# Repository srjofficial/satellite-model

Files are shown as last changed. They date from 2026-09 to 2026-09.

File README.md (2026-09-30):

# 🛰️ CubeSat-Style 1U Satellite Working Model








A comprehensive, fully open-source **1U CubeSat educational demonstrator (100 mm cube)** featuring autonomous dual-axis solar tracking, an ESP32-CAM imaging payload, environmental & electrical telemetry, and long-range LoRa packet downlink with automated ground station reassembly.

---

## 🖼️ 3D Model & PCB Previews

| 🛰️ 3D CAD Assembly (OpenSCAD / WebGL) | 🟢 Carrier PCB & Gerber Layout |
|:---:|:---:|
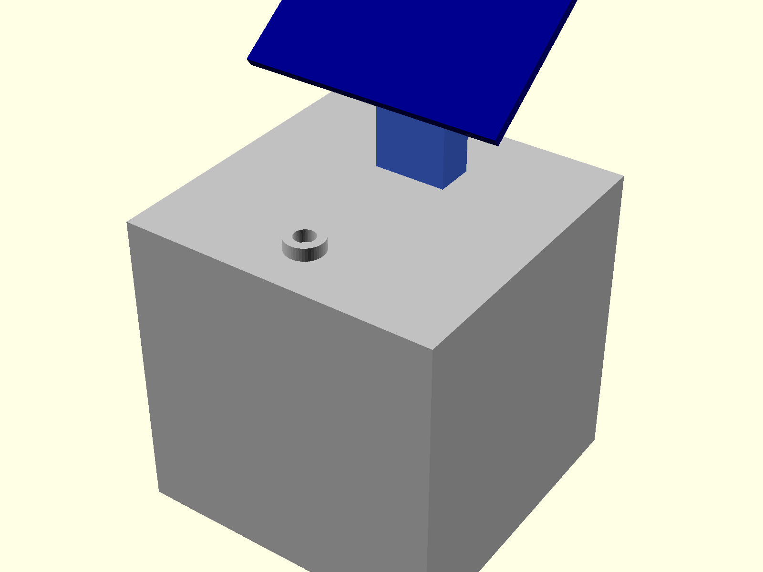
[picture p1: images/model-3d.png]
CubeSat 3D Model
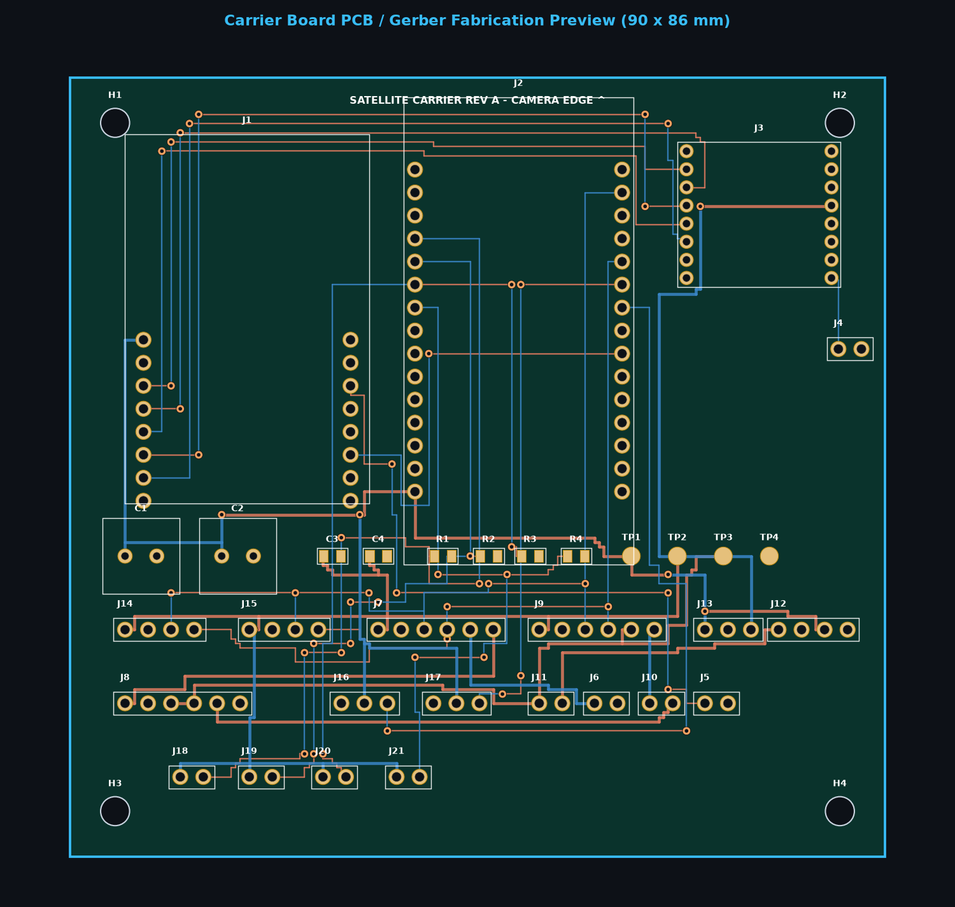
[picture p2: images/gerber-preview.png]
Carrier PCB Gerber Preview
|  |  |
| *100 mm 1U chassis with pan/tilt solar tracker & camera aperture* | *90 × 86 mm 2-layer PCB layout with routed traces, ENIG pads & silkscreen* |

* 🌐 **Interactive 3D Web Viewer:** Open [`cad/view_model.html`](cad/view_model.html) in your browser for full 3D Orbit controls, real-time Pan/Tilt servo simulation, and an **Exploded View**!
* 📦 **PCB Fabrication Files:** Download [`hardware/gerbers.zip`](hardware/gerbers.zip) for instant manufacturing (JLCPCB, PCBWay, OSHPark).
* 🧪 **Proteus Integration:** Tango netlist and simulation guide available in [`hardware/proteus/`](hardware/proteus/).

```powershell
# Open interactive 3D model viewer in your browser
Start-Process "cad\view_model.html"
```

---

## 🚀 Key Features

* **☀️ Autonomous Dual-Axis Solar Tracking:** 4-quadrant LDR contrast bridge driving two SG90/MG90S servos across pan (10°–170°) and tilt (20°–160°) axes with software deadband and smooth 1° increments.
* **📸 Chunked LoRa Imaging Payload:** AI-Thinker ESP32-CAM captures QQVGA (160×120) JPEG stills, slices them into 200-byte packets protected by CRC-16/CCITT-FALSE checksums, and transmits over SX1278 LoRa.
* **⚡ Comprehensive Telemetry Suite:** Dual INA219 sensors (solar generation V/mA and battery charge/discharge V/mA), Bosch BME280 (temperature, atmospheric pressure, relative humidity), and MPU6050 6-DOF IMU (real-time pitch/roll attitude).
* **🔋 Power Management & Duty Cycling:** Single 18650 Li-ion battery charged via TP4056 with DW01 low-voltage protection, 5V boost converter, dedicated 3.3V LDO, and deep-sleep duty cycling on the camera payload.
* **📡 Ground Station & Python Reassembly:** ESP32 + SX1278 receiver firmware that validates hardware & software CRC-16 checksums, paired with a Python application that reconstructs JPEG images and logs synchronized telemetry to CSV.
* **🛠️ Parametric CAD & Carrier PCB:** Parametric OpenSCAD design (`cad/satellite.scad`) matched to a custom 90×86 mm 2-layer KiCad carrier PCB (`hardware/kicad/`) with ground pours, M3 standoffs, and antenna keep-out zones.

---

## 🏗️ System Architecture

```mermaid
flowchart TD
  subgraph EPS["Electrical Power Subsystem (EPS)"]
    SP["☀️ Solar Panel (Max 6V)"] --> J7["INA219 #1 (Solar V & mA)"]
    J7 --> CH["TP4056 Charger + DW01 Protection"]
    CH <--> J9["INA219 #2 (Battery V & +/-mA)"]
    J9 <--> BAT["🔋 18650 Li-ion Cell (3.7V)"]
    CH --> SW["Power Switch"]
    SW --> BST["⚡ 5V Boost Converter"]
    BST --> RAIL5["+5V Power Rail"]
    RAIL5 --> LDO["AMS1117-3.3 LDO"]
    LDO --> RAIL3["+3.3V Power Rail"]
  end

  subgraph OAS["OBC & Attitude Subsystem (Tracker)"]
    RAIL5 --> TRK["ESP32 DevKit 30-Pin"]
    LDR["4x LDR Quadrant Bridge"] --> TRK
    BME["BME280 (Temp/Press/Hum)"] -->|"I2C (0x76)"| TRK
    MPU["MPU6050 (Pitch/Roll)"] -->|"I2C (0x68)"| TRK
    J7 -->|"I2C (0x40)"| TRK
    J9 -->|"I2C (0x41)"| TRK
    TRK -->|"PWM GPIO 18"| SRV1["Pan Servo (10°-170°)"]
    TRK -->|"PWM GPIO 19"| SRV2["Tilt Servo (20°-160°)"]
  end

  subgraph PAYLOAD["Camera Payload & Communications"]
    RAIL5 --> CAM["AI-Thinker ESP32-CAM"]
    RAIL3 --> LORA["SX1278 LoRa Module (433 MHz)"]
    TRK -->|"UART2 115200 (GPIO 17 to GPIO 3)"| CAM
    CAM -->|"HSPI (SCK 14, MISO 12, MOSI 13, NSS 15)"| LORA
  end

  subgraph GROUND["Ground Segment"]
    LORA -.->|"LoRa RF 433 MHz (SF7, BW 125kHz)"| GS_RF["Ground SX1278"]
    GS_RF --> GS_MCU["Ground ESP32 DevKit"]
    GS_MCU -->|"USB Serial (PKT, hex, rssi, snr)"| PY["Python Ground Station App"]
    PY --> CSV["📊 telemetry.csv"]
    PY --> JPG["🖼️ Reassembled JPEGs"]
  end
```

---

## 📦 Downlink Protocol & Packet Format

Telemetry and image chunks are packed into byte frames protected by **CRC-16/CCITT-FALSE** (`poly=0x1021`, `init=0xFFFF`):

| Offset (Bytes) | Field | Description |
|:---:|:---|:---|
| `0` | **Type** | `0x10` = Image Chunk, `0x20` = Telemetry |
| `1` | **Image ID** | Sequential image session ID (0–255, wraps) |
| `2..3` | **Sequence No** | 16-bit big-endian chunk index (0-based) |
| `4..5` | **Total Packets** | 16-bit big-endian total chunk count for image |
| `6` | **Length ($N$)** | Payload length ($\le 200$ bytes) |
| `7 .. 6+N` | **Payload** | Raw JPEG chunk or ASCII CSV telemetry string |
| `7+N .. 8+N` | **CRC-16** | CRC-16/CCITT calculated over bytes `0` through `6+N` |

### Telemetry String Structure
Transmitted over UART from the Tracker MCU to the Camera payload once per second:
```csv
T,solarV,solar_mA,battV,batt_mA,tempC,pressHPa,humPct,pitch,roll,pan,tilt
```

---

## 🗂️ Repository Structure

```
satellite-model/
├── cad/
│   ├── satellite.scad          # Parametric OpenSCAD 1U cube model
│   ├── view_model.html         # Interactive WebGL 3D model viewer
│   └── README.md               # 3D export instructions (STL/STEP)
├── firmware/
│   ├── esp32-cam-node/         # Camera payload, packetizer, LoRa TX, sleep
│   ├── solar-tracker/          # 4-quadrant LDR tracking, I2C sensors, servos
│   └── ground-station/         # ESP32 + LoRa receiver with CRC verification
├── ground-station-ui/
│   ├── ground_station.py       # Python image reassembly & CSV telemetry logger
│   └── requirements.txt        # Python dependencies (pyserial)
├── hardware/
│   ├── bom.csv                 # Detailed Bill of Materials
│   ├── netlist.csv             # Complete pin-to-pin electrical netlist
│   ├── pinmap.md               # Pin assignment documentation
│   └── kicad/
│       ├── generate_kicad.py   # Algorithmic router & KiCad project generator
│       ├── satellite.kicad_sch # Carrier board schematic
│       ├── satellite.kicad_pcb # Routed 2-layer PCB (90x86 mm)
│       ├── satellite.kicad_pro # KiCad 8 project configuration
│       ├── satellite.pretty/   # Custom footprints
│       └── pcb-preview.png     # Rendered PCB preview
└── docs/
    ├── architecture.md         # Subsystem dataflow & packet specification
    ├── power-budget.md         # Power consumption estimates & duty cycle formula
    ├── test-results.md         # Test result template
    └── linkedin-post.md        # Summary post template
```

---

## 🔧 Bill of Materials (BOM)

| Ref | Component | Description | Qty |
|---|---|---|:---:|
| **U1 / J1** | AI-Thinker ESP32-CAM | Camera payload node (OV2640) | 1 |
| **U2 / J2** | ESP32 DevKit (30-pin) | Solar tracker & telemetry aggregator | 1 |
| **U3 / J3** | SX1278 Ra-02 (433 MHz) | LoRa transceiver module (satellite node) | 1 |
| **U4** | SX1278 Ra-02 + ESP32 | Ground station receiver node | 1 |
| **SEN1 / J7** | INA219 Breakout | Solar current & voltage monitor (`0x40`) | 1 |
| **SEN2 / J9** | INA219 Breakout | Battery current & voltage monitor (`0x41`, solder A0) | 1 |
| **SEN3 / J14**| BME280 Breakout | Temperature, pressure, humidity (`0x76`) | 1 |
| **SEN4 / J15**| MPU6050 Breakout | 6-DOF Gyro & Accelerometer (`0x68`) | 1 |
| **ACT1, ACT2**| SG90 or MG90S | Pan & Tilt servos | 2 |
| **PWR1 / J8** | TP4056 Module | Li-ion charger with DW01 protection | 1 |
| **PWR2 / J12**| MT3608 Boost Module | 3.7V to 5.0V step-up DC-DC converter | 1 |
| **PWR3 / J13**| AMS1117-3.3 Module | 5.0V to 3.3V dedicated LDO | 1 |
| **BAT / J10** | 18650 Li-ion Cell | 3.7V nominal, 2000–3000 mAh + holder | 1 |
| **PV / J6** | Mini Solar Panel | $\le 6\text{ V}$ open circuit (50–150 mA) | 1 |
| **LDR1–4** | GL5528 LDR + 10k 0805 | Quadrant light detection dividers | 4 |
| **C1, C2** | 470 µF 10V Radial | 5V rail bulk capacitors for servo surge absorption | 2 |

---

## ⚡ Setup & Flashing Instructions

### 1. Arduino IDE Setup
Install the **ESP32 Board Package** in Arduino IDE and install the following libraries via the Library Manager:
* `LoRa` (by Sandeep Mistry)
* `ESP32Servo` (by Kevin Harrington)
* `Adafruit INA219`
* `Adafruit BME280 Library`
* `Adafruit MPU6050`
* `Adafruit Unified Sensor`

### 2. Flashing the Tracker Node
1. Open [`firmware/solar-tracker/solar-tracker.ino`](firmware/solar-tracker/solar-tracker.ino).
2. Board: **ESP32 Dev Module** (30-pin DevKit).
3. Connect USB and click **Upload**.

### 3. Flashing the ESP32-CAM Node
> ⚠️ **IMPORTANT:** Disconnect the tracker telemetry line (`ESP32-CAM RX / GPIO 3`) and short `GPIO 0` to `GND` before powering on to enter flashing mode.
1. Open [`firmware/esp32-cam-node/esp32-cam-node.ino`](firmware/esp32-cam-node/esp32-cam-node.ino).
2. Board: **AI Thinker ESP32-CAM**.
3. Upload using an external USB-to-UART adapter (5V, GND, U0TXD, U0RXD).
4. Remove the `GPIO 0` to `GND` jumper and reconnect the telemetry wire after flashing.

### 4. Flashing the Ground Station
1. Open [`firmware/ground-station/ground-station.ino`](firmware/ground-station/ground-station.ino).
2. Connect the ground station ESP32 and click **Upload**.

### 5. Running the Ground Station App
```bash
# Navigate to the ground station directory
cd ground-station-ui

# Install dependencies
pip install -r requirements.txt

# Run the receiver (replace COM5 with your port, or /dev/ttyUSB0 on Linux/macOS)
python ground_station.py --port COM5
```
* **Telemetries:** Appended in real-time to `received/telemetry.csv` with timestamps, signal RSSI, and SNR.
* **Images:** Fully reassembled JPEGs saved automatically to `received/img_<id>_<timestamp>.jpg`.

---

## 📊 Power Budget & Battery Life

| Subsystem / Component | State | Current @ 5V / 3.3V |
|---|---|:---:|
| **ESP32 DevKit (Tracker)** | Active (Tracking & Reading Sensors) | ~50–70 mA |
| **Dual Servos (SG90/MG90S)**| Moving / Idle | ~150–500 mA (peak) / ~10 mA |
| **Sensors (INA219 x2, BME280, MPU6050)** | Active I2C | ~5 mA |
| **ESP32-CAM (Payload)** | Capture & LoRa TX (~5–8s burst) | ~200–280 mA |
| **ESP32-CAM (Payload)** | Deep Sleep (Duty cycle between shots) | ~6–8 mA |

* **Duty Cycle Formula:**
  $$I_{\text{avg}} = \frac{I_{\text{active}} \cdot t_{\text{active}} + I_{\text{sleep}} \cdot t_{\text{sleep}}}{t_{\text{active}} + t_{\text{sleep}}}$$
* With an average consumption of ~120 mA and a single 2500 mAh 18650 cell, expected continuous operation without sunlight is **16–20+ hours**, extended indefinitely under active solar tracking.

---

## 📜 License

This project is open-source under the [MIT License](LICENSE).
Feel free to use it for academic, research, or personal educational projects!

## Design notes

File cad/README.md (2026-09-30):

# CAD

`satellite.scad` is a parametric OpenSCAD model: 100 mm hollow cube body, camera window, antenna mount, bottom plate with PCB standoffs, and a pan/tilt servo mount holding a solar panel.

Export STL:
```
openscad -D 'part="body"' -o body.stl satellite.scad
openscad -D 'part="base"' -o base.stl satellite.scad
openscad -D 'part="tracker"' -o tracker.stl satellite.scad
```
Add `.stl` (and `.step` if exported from FreeCAD) files here. Check dimensions against your real servos and panel before printing. The tracker part is a visual mount; the printable bracket needs fitting to your servo horn.

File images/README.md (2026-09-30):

Add here: build photos, wiring photo, `demo.gif`, received sample images, 3D render (`assembly.png`), block diagram.

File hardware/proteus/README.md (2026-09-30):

# Proteus Design Suite Guide

## Why is `.pdsprj` not directly included?
A `.pdsprj` file is a **proprietary, compiled binary archive** created by Labcenter Electronics Proteus. Inside the `.pdsprj` container are closed-source compiled database files (`ROOT.DSN` for ISIS and `LAYOUT.LYT` for ARES) that can **only be created natively by the Proteus software engine itself**. Any third-party file manually named `.pdsprj` will produce a "Corrupt or invalid project file" error in Proteus.

---

## How to use this project in Proteus

### 1. View the PCB in Proteus Gerber Viewer
Proteus has a built-in Gerber & Excellon viewer:
1. Open **Proteus**.
2. Click **Gerber Viewer** on the startup page (or go to `Output` > `Gerber/Excellon Output` > `Launch Gerber Viewer`).
3. Click `File` > `Open Gerber` and select the files from `hardware/gerbers/` (or extract `hardware/gerbers.zip`).
4. Proteus will render all copper layers, solder masks, silkscreen, and drill holes.

### 2. Import Netlist into Proteus ARES (PCB Layout)
If you want to route or modify the carrier board in Proteus ARES:
1. In Proteus, open **ARES PCB Layout**.
2. Go to `Tools` > `Netlist Compiler` (or `File` > `Import Netlist`).
3. Select `satellite_tango.net` (standard Tango netlist format provided in this directory).
4. Assign footprints for the module headers (`J1` to `J21`, passives `R1-R4`, `C1-C4`).
5. Proteus will load all 24 connected electrical nets.

### 3. Simulating the Circuit in Proteus ISIS
To simulate the CubeSat subsystems in Proteus ISIS:
* **Microcontroller:** Place an `ESP32-WROOM-32` or `Arduino Uno/Nano` (available in the Proteus component library).
* **Solar Tracker:** Place 4 `TORCH_LDR` components in a bridge with four `10k` resistors to analog ADC pins (`IO34, IO35, IO32, IO33`), and connect two `MOTOR-SERVO` components to PWM pins `IO18` and `IO19`.
* **Firmware:** Load the compiled `.hex` or `.bin` from Arduino IDE (`firmware/solar-tracker/`) into the microcontroller properties.

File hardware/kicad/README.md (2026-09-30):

# KiCad project (carrier board, rev A)

Open `satellite.kicad_pro` in **KiCad 8 or newer**.

| File | Contents |
|---|---|
| `satellite.kicad_sch` | Schematic: every module as a header symbol, nets joined by labels |
| `satellite.kicad_pcb` | 90 x 86 mm 2-layer board, placed and routed, GND pour on both layers, antenna keep-out |
| `satellite.pretty/` | Footprints (headers, module sockets, 0805, radial cap, test point, M3 hole) |
| `generate_kicad.py` | Regenerates everything above and `../netlist.csv` (`python3 generate_kicad.py`) |
| `pcb-preview.png` | Picture of the routed board |

## How the board works
Nothing is soldered directly to the board except headers and small passives. Modules (ESP32-CAM, ESP32 DevKit, Ra-02 LoRa, TP4056, boost, LDO, INA219 x2, BME280, MPU6050) plug into or wire to headers. Servos, LDRs, solar panel, battery holder and switch connect through 2-3 pin headers.

Mounting holes: M3 at 80 x 76 mm spacing (matches `cad/satellite.scad`). The top edge (y = 0) is the camera edge.

## First steps in KiCad
1. Open the PCB, press **B** to fill zones, then run **Inspect > Design Rules Checker**.
2. Open the schematic, run **Inspect > Electrical Rules Checker**. Expect warnings about passive pins; every pin is typed "passive" on purpose.
3. **Tools > Update PCB from Schematic** should report no changes.
4. Check the 3D viewer, then **File > Fabrication Outputs > Gerbers/Drill** and save to `gerbers/`.

## What was and was not checked
Checked by script: file syntax (balanced S-expressions), every schematic label sits on a pin, all 24 signal/power nets routed, minimum copper clearance 0.216 mm against a 0.2 mm rule, nothing inside the antenna keep-out or near the edge.

**Not checked:** I could not open these files in KiCad itself. Expect small load or DRC surprises. Fix them in KiCad rather than re-running the script if you have already edited the board.

## Verify before ordering a board
- **Module pinouts vary by clone.** Compare the ESP32-CAM, DevKit, Ra-02, INA219 and TP4056 pin order and row spacing against your actual modules. Row spacing is set in `generate_kicad.py` (`ROW_CAM`, `ROW_DEV`); edit and re-run.
- Servo and boost traces are 0.8 mm; signals 0.4 mm. Servo stall current can exceed what one 18650 through a boost converter delivers. Keep the 470 uF capacitors.
- The battery path goes through INA219 #2 (0.1 ohm shunt), so peak load current drops roughly 0.1 V per amp.
- GPIO12 (LoRa MISO) is an ESP32 boot-strap pin and GPIO2 (LoRa RESET) must be low or floating to flash; unplug the LoRa module if flashing fails.
- Label the board "untested design" until built and tested.

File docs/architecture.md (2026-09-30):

# Architecture

## Subsystems
1. **Power (EPS):** Solar panel -> TP4056 (protected) -> 18650 -> 5 V boost -> both ESP32 boards. Dedicated 3.3 V LDO for LoRa + I2C sensors.
2. **Attitude/solar tracking:** 4-quadrant LDR bridge read by ESP32 ADC. Top/bottom difference drives tilt servo, left/right difference drives pan servo (1 degree steps, deadband).
3. **Payload:** ESP32-CAM captures QQVGA JPEG on a timer.
4. **Comms:** SX1278 LoRa (SF7, BW 125 kHz, CR 4/5). Packets carry CRC-16/CCITT.
5. **Ground segment:** ESP32 + SX1278 forwards verified packets over USB serial; Python reassembles.

## Data flow
Tracker (1 Hz) --UART text--> CAM node. CAM wakes from deep sleep every `SLEEP_SECONDS`, grabs the latest telemetry line, captures an image, transmits telemetry packet + image chunks, sleeps.

## Packet format (big-endian)
| Bytes | Field |
|---|---|
| 1 | type: `0x10` image data, `0x20` telemetry |
| 1 | image id (wraps at 255) |
| 2 | sequence number (0-based) |
| 2 | total packets |
| 1 | payload length |
| N | payload (<= 200 B) |
| 2 | CRC-16/CCITT-FALSE over all previous bytes |

## Telemetry line
`T,solarV,solarmA,battV,battmA,tempC,pressHPa,humPct,pitch,roll,pan,tilt`

## Block diagram
Export the Mermaid diagram in the README to `docs/block-diagram.png` (mermaid.live) and commit it.

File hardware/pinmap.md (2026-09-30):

# Pin Map

Board references (J1, J2...) match `hardware/kicad/`. Full connection list: `netlist.csv` (generated from the same table as the schematic and PCB).

## ESP32-CAM (AI-Thinker), J1 - camera node
| Signal | GPIO | Connects to |
|---|---|---|
| LoRa SCK | 14 | SX1278 SCK |
| LoRa MISO | 12 | SX1278 MISO |
| LoRa MOSI | 13 | SX1278 MOSI |
| LoRa NSS | 15 | SX1278 NSS |
| LoRa RST | 2 | SX1278 RESET |
| LoRa DIO0 | not used | TX-only firmware |
| Telemetry RX (UART0) | 3 | Tracker GPIO17 (disconnect when flashing) |
| Flash jumper | 0 | J5 (short IO0 to GND only while flashing) |
| 5V / GND | - | Boost output / GND |
| 3V3 for LoRa | - | Dedicated 3.3 V LDO (J13); the board's own 3V3 pin is left unconnected |

## ESP32 DevKit, J2 - tracker
| Signal | GPIO |
|---|---|
| Pan servo (J16) | 18 |
| Tilt servo (J17) | 19 |
| LDR TL / TR / BL / BR (J18-J21) | 34 / 35 / 32 / 33 |
| I2C SDA / SCL | 21 / 22 |
| UART2 TX (to CAM RX) | 17 |

I2C devices: INA219 solar (J7) 0x40, INA219 battery (J9) 0x41 (solder A0), BME280 (J14) 0x76, MPU6050 (J15) 0x68.

LDR wiring: 3.3 V -> LDR (J18-J21) -> ADC pin -> 10 kOhm (R1-R4) -> GND.

## Power path
Solar (J6) -> INA219 (J7) -> TP4056 IN -> TP4056 B+ -> INA219 (J9) -> 18650 (J10). Load takes TP4056 OUT+ -> switch (J11) -> 5 V boost (J12) -> 5 V rail -> 3.3 V LDO (J13).

TP4056 header (J8) pin order matches standard protected module pads:
1: IN+, 2: IN-, 3: OUT+, 4: B+, 5: B-, 6: OUT-.

## SX1278 Ra-02, J3 and ground station
Note for J3 on carrier board: Verify your Ra-02 breakout module pinout against J3 before soldering (bare modules use 2.0 mm pitch; check pin assignments).
Ground-station ESP32 DevKit wiring (separate, not on this board):

| Signal | GPIO |
|---|---|
| SCK / MISO / MOSI | 18 / 19 / 23 |
| NSS / RST / DIO0 | 5 / 14 / 26 |

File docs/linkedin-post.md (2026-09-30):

# 🚀 LinkedIn Post Templates

Here are ready-to-publish post templates crafted for maximum engagement, showcasing both hardware engineering and embedded software skills.

---

## 🌟 Option 1: Engineering Story & Technical Deep Dive (Recommended)

Can you transmit images from a satellite using only long-range radio (LoRa)? 🛰️📡

I recently engineered a functional **1U CubeSat Satellite Model (100 mm cube)** from scratch—combining embedded systems, custom PCB design, solar tracking, and a long-range downlink.

Here’s how the subsystems work together:

☀️ **Dual-Axis Solar Tracker:**
A 4-quadrant LDR contrast bridge and ESP32 DevKit compute sunlight differentials to steer dual micro-servos across pan (10°–170°) and tilt (20°–160°) angles with software deadbanding.

📸 **Payload & LoRa Image Downlink:**
LoRa runs at low bitrates (~5 kbps at SF7/125kHz), making live video impossible. Instead, I designed a chunked downlink protocol: an AI-Thinker ESP32-CAM captures QQVGA (160x120) JPEG stills, slices them into 200-byte packets protected by CRC-16/CCITT-FALSE checksums, and transmits them over a 433 MHz SX1278 transceiver.

⚡ **Electrical Power Subsystem (EPS):**
A single 18650 Li-ion cell charged via TP4056 + DW01 protection, stepped up to 5V (MT3608) and 3.3V (AMS1117). Real-time solar and battery power telemetry are monitored using dual INA219 current/voltage sensors, while the camera node duty-cycles into deep sleep to maximize battery life.

📊 **Sensors & Ground Station:**
Monitors attitude via MPU6050 (pitch/roll) and environment via BME280 (temperature, atmospheric pressure, relative humidity). A dedicated ground station receiver forwards verified packets over USB serial to a custom Python desktop application that logs telemetry to CSV and automatically reassembles incoming JPEG images.

🛠️ **Hardware & CAD:**
- Designed a custom 90×86 mm 2-layer carrier PCB in KiCad 8.0 with dedicated ground pours and antenna keep-outs.
- Modeled a parametric 1U enclosure in OpenSCAD with an interactive WebGL 3D viewer built with Three.js.

Huge thanks to the open-source hardware community for making space technology concepts accessible for hands-on learning.

🔗 Full source code, schematics, and CAD files on GitHub:
https://github.com/srjofficial/satellite-model

#EmbeddedSystems #CubeSat #ESP32 #LoRa #PCBDesign #HardwareEngineering #OpenSource #IoT #KiCad #Arduino #SpaceTech

---

## ⚡ Option 2: Short & Punchy Portfolio Showcase

Thrilled to share my latest hardware & firmware project: a functional **1U CubeSat Satellite Working Model**! 🛰️⚡

Key features:
✅ Autonomous dual-axis solar tracking (4-quadrant LDR + dual servos)
✅ ESP32-CAM payload transmitting compressed JPEGs over SX1278 LoRa (433 MHz)
✅ CRC-16 protected packet protocol with automated Python image reassembly
✅ Comprehensive telemetry: Dual INA219 (V/I), BME280 (P/T/H), MPU6050 (attitude)
✅ Custom 2-layer KiCad 8 carrier PCB + parametric OpenSCAD 3D chassis

One of the best engineering lessons on this build was architecting around bandwidth constraints—turning a low-throughput LoRa radio into a reliable image downlink using custom chunking and CRC validation.

Check out the full repository (code, CAD, and schematics):
👉 https://github.com/srjofficial/satellite-model

#IoT #Embedded #ESP32 #CubeSat #Electronics #AerospaceEngineering #Robotics #Hardware

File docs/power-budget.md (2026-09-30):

# Power Budget

Values below are **typical datasheet-level estimates. Replace with your INA219 measurements.**

| Load | Mode | Current (mA) | Notes |
|---|---|---|---|
| ESP32-CAM | capture + processing | ~150-200 | camera on |
| SX1278 | TX 17 dBm | ~90-120 | during packets only |
| ESP32-CAM | deep sleep | ~6-10 | AI-Thinker board overhead |
| ESP32 DevKit tracker | active | ~50-80 | WiFi/BT off |
| Servos | idle / moving | ~10 / 150-500 | move rarely |
| Sensors (INA219, BME280, MPU6050) | active | ~5 | |

## Battery
18650 nominal ~2000-3000 mAh at 3.7 V. Boost efficiency ~85%.

## Duty-cycle formula
`I_avg = (I_active * t_active + I_sleep * t_sleep) / (t_active + t_sleep)`

Fill in measured values:

| Cycle time | t_active (s) | I_avg (mA) | Runtime without sun (h) |
|---|---|---|---|
| 60 s | TBD | TBD | TBD |
| 300 s | TBD | TBD | TBD |

## Solar
Panel: TBD V / TBD mA. Measure charge current at noon vs. tracker fixed vs. tracking on.

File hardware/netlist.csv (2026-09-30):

net | pins
GND | J1.2(GND), J1.12(GND), J1.16(GND), J2.14(GND), J2.29(GND), J3.1(GND), J3.8(GND), J3.10(GND), J4.2(GND), J5.2(GND), J6.2(PV-), J7.2(GND), J8.2(IN-), J8.6(OUT-), J9.2(GND), J12.2(VIN-), J12.4(VOUT-), J13.2(GND), J14.2(GND), J15.2(GND), J16.1(GND), J17.1(GND), R1.2(2), R2.2(2), R3.2(2), R4.2(2), C1.2(-), C2.2(-), C3.2(2), C4.2(2), TP4.1(1)
+5V | J1.1(5V), J2.15(VIN), J12.3(VOUT+), J13.1(VIN), J16.2(V+), J17.2(V+), C1.1(+), C2.1(+), TP1.1(1)
LORA_MISO | J1.3(IO12), J3.2(MISO)
LORA_MOSI | J1.4(IO13), J3.3(MOSI)
LORA_NSS | J1.5(IO15), J3.5(NSS)
LORA_SCK | J1.6(IO14), J3.4(SCK)
LORA_RST | J1.7(IO2), J3.6(RESET)
CAM_IO0 | J1.11(IO0), J5.1(IO0)
UART_TELEM | J1.14(U0R), J2.24(IO17_TX2)
LDR_TL | J2.4(IO34), J18.2(SIG), R1.1(1)
LDR_TR | J2.5(IO35), J19.2(SIG), R2.1(1)
LDR_BL | J2.6(IO32), J20.2(SIG), R3.1(1)
LDR_BR | J2.7(IO33), J21.2(SIG), R4.1(1)
I2C_SCL | J2.17(IO22), J7.3(SCL), J9.3(SCL), J14.3(SCL), J15.3(SCL)
I2C_SDA | J2.20(IO21), J7.4(SDA), J9.4(SDA), J14.4(SDA), J15.4(SDA)
SERVO_TILT | J2.21(IO19), J17.3(SIG)
SERVO_PAN | J2.22(IO18), J16.3(SIG)
LORA_ANT | J3.9(ANT), J4.1(ANT)
+3V3 | J3.13(3V3), J7.1(VCC), J9.1(VCC), J13.3(VOUT), J14.1(VCC), J15.1(VCC), J18.1(3V3), J19.1(3V3), J20.1(3V3), J21.1(3V3), C3.1(1), C4.1(1), TP2.1(1)
SOLAR_IN | J6.1(PV+), J7.5(VIN+)
SOLAR_OUT | J7.6(VIN-), J8.1(IN+)
TP_BP | J8.3(OUT+), J8.4(B+), J9.5(VIN+), J11.1(IN), TP3.1(1)
BAT_NEG | J8.5(B-), J10.2(BAT-)
BAT_POS | J9.6(VIN-), J10.1(BAT+)
VBAT_SW | J11.2(OUT), J12.1(VIN+)

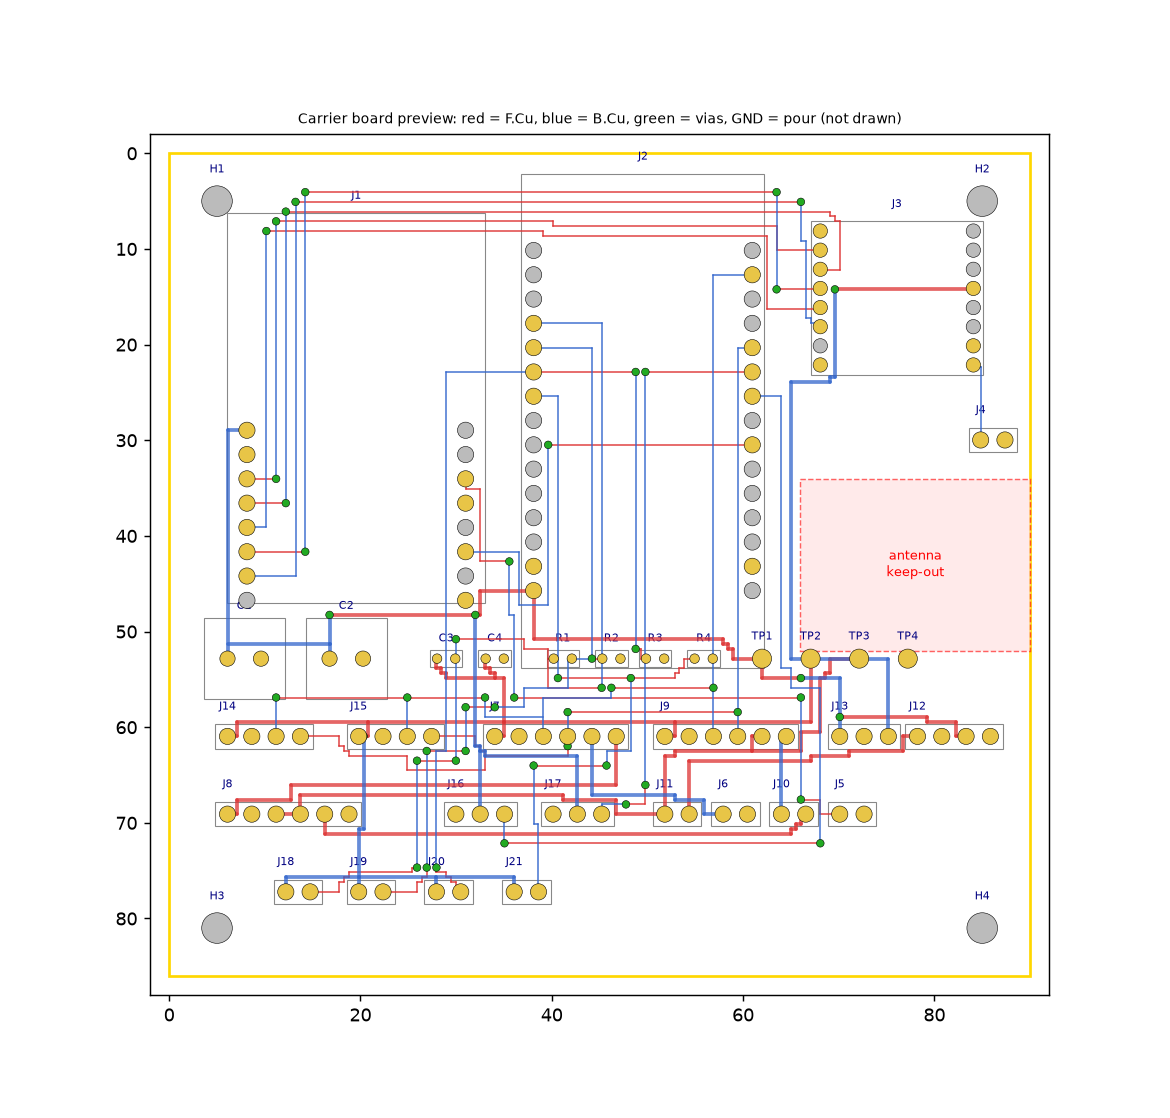
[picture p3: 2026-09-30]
hardware/kicad/pcb-preview.png

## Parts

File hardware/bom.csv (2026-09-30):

ref | part | qty | notes
J1 | AI-Thinker ESP32-CAM + 2x 1x8 female header | 1 | camera node
J2 | ESP32 DevKit 30-pin + 2x 1x15 female header | 1 | tracker/telemetry; check row spacing
J3 | SX1278 Ra-02 433 MHz module | 1 | solder to board or use 2.0 mm adapter; second one for ground station
J4 | 1x2 pin header | 1 | LoRa antenna pigtail / wire
J5 J6 J10 J11 | 1x2 pin header | 4 | flash jumper / solar / battery holder / switch
J7 J9 | INA219 breakout + 1x6 header | 2 | set second to 0x41 (solder A0)
J8 | TP4056 module with DW01 protection + 1x6 header | 1
J12 | 5V boost module (MT3608 or similar) + 1x4 header | 1 | set 5.0 V before connecting
J13 | 3.3V LDO module (AMS1117-3.3) + 1x3 header | 1
J14 J15 | BME280 and MPU6050 breakouts + 1x4 header | 2 | BME280 address 0x76
J16 J17 | SG90 or MG90S servo + 1x3 header | 2 | pan / tilt
J18-J21 | LDR (GL5528 or similar) + 1x2 header | 4 | quadrant sun sensor
R1-R4 | 10k 0805 resistor | 4 | LDR dividers
C1 C2 | 470 uF 10 V radial 8 mm | 2 | 5 V bulk
C3 | 10 uF 0805 | 1 | 3.3 V
C4 | 100 nF 0805 | 1 | 3.3 V
TP1-TP4 | Test pad 2 mm | 4 | +5V / +3V3 / VBAT / GND
H1-H4 | M3 screw + 6 mm standoff | 4
PV1 | Solar panel 5-6V small | 1 | open-circuit voltage must stay <= 6 V
BT1 | 18650 cell + holder | 1 | protected cell recommended
ANT1 | 433 MHz antenna | 2 | one per LoRa module
- | 3D-printed frame (PLA/PETG) | 1 | see cad/

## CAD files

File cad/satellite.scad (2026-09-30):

// CubeSat-style 1U-ish model (100 mm cube), parametric.
// Export: openscad -D 'part="body"' -o body.stl satellite.scad
// part = "assembly" | "body" | "base" | "tracker" | "panel"
part = "assembly";
$fn = 48;
S = 100;        // cube size
W = 2.5;        // wall
tilt = 35;      // panel tilt for preview

module servo() {
  color("royalblue") cube([23, 12.5, 22.5], center = true);
  color("white") translate([0, 0, 11.25]) cylinder(d = 6, h = 4);
}

module panel() { color("navy") cube([80, 60, 3], center = true); }

module body() {
  difference() {
    cube([S, S, S], center = true);
    // hollow, open bottom for assembly
    translate([0, 0, -W / 2]) cube([S - 2 * W, S - 2 * W, S - W + 0.02], center = true);
    // camera window on +Y face (offset -25.6 mm to align with PCB socket J1)
    translate([-25.6, S / 2 - W / 2, -26]) rotate([90, 0, 0]) cylinder(d = 14, h = W + 2, center = true);
    // power switch slot on -X face
    translate([-S / 2, 0, -20]) cube([W * 2 + 1, 12, 7], center = true);
    // antenna hole on top, rear
    translate([0, -35, S / 2]) cylinder(d = 6.5, h = W * 3, center = true);
    // cable hole for tracker servos (top, centre)
    translate([0, 20, S / 2]) cube([10, 10, W * 3], center = true);
  }
  // antenna mount boss
  translate([0, -35, S / 2 + 2]) difference() {
    cylinder(d = 12, h = 4);
    translate([0, 0, -1]) cylinder(d = 6.5, h = 6);
  }
}

module base() {
  difference() {
    translate([0, 0, -S / 2 - W / 2]) cube([S - 2 * W - 0.6, S - 2 * W - 0.6, W], center = true);
    for (x = [-40, 40], y = [-38, 38]) translate([x, y, -S / 2]) cylinder(d = 3.2, h = 10, center = true);
  }
  // PCB standoffs (80 x 76 mm hole pattern matches the KiCad board)
  for (x = [-40, 40], y = [-38, 38]) translate([x, y, -S / 2 + 3]) difference() {
    cylinder(d = 7, h = 6, center = true);
    cylinder(d = 2.8, h = 7, center = true);
  }
}

module tracker() {
  translate([0, 20, S / 2]) {
    translate([0, 0, 11.25]) servo();                      // pan servo
    translate([0, 0, 22.5 + 4]) {
      color("gray") cylinder(d = 24, h = 2);               // turntable
      for (x = [-18, 18]) translate([x, 0, 11]) color("gray") cube([2, 14, 20], center = true);
      translate([-25, 0, 11]) rotate([0, 90, 0]) servo();  // tilt servo
      translate([0, 0, 21]) rotate([tilt, 0, 0]) translate([0, 0, 4]) panel();
    }
  }
}

if (part == "assembly") { color("silver") body(); color("darkgray") base(); tracker(); }
else if (part == "body") body();
else if (part == "base") base();
else if (part == "tracker") tracker();
else if (part == "panel") panel();

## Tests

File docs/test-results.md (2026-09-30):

# Test Results

Fill in real measurements. Do not publish estimates as results.

| Test | Method | Result | Date |
|---|---|---|---|
| LoRa range (line of sight) | Move RX away, log RSSI/loss | TBD | |
| Image delivery rate | 20 captures, count complete images | TBD | |
| Avg image airtime | Timestamps from ground_station.py | TBD | |
| Tracking accuracy | Lamp/sun, measure panel angle error | TBD | |
| Charge current: fixed vs tracking | INA219 log over 1 h | TBD | |
| Deep-sleep current | Multimeter/INA219 | TBD | |
| Battery runtime | Full charge to cutoff | TBD | |

Attach logs to `images/` or a `data/` folder.

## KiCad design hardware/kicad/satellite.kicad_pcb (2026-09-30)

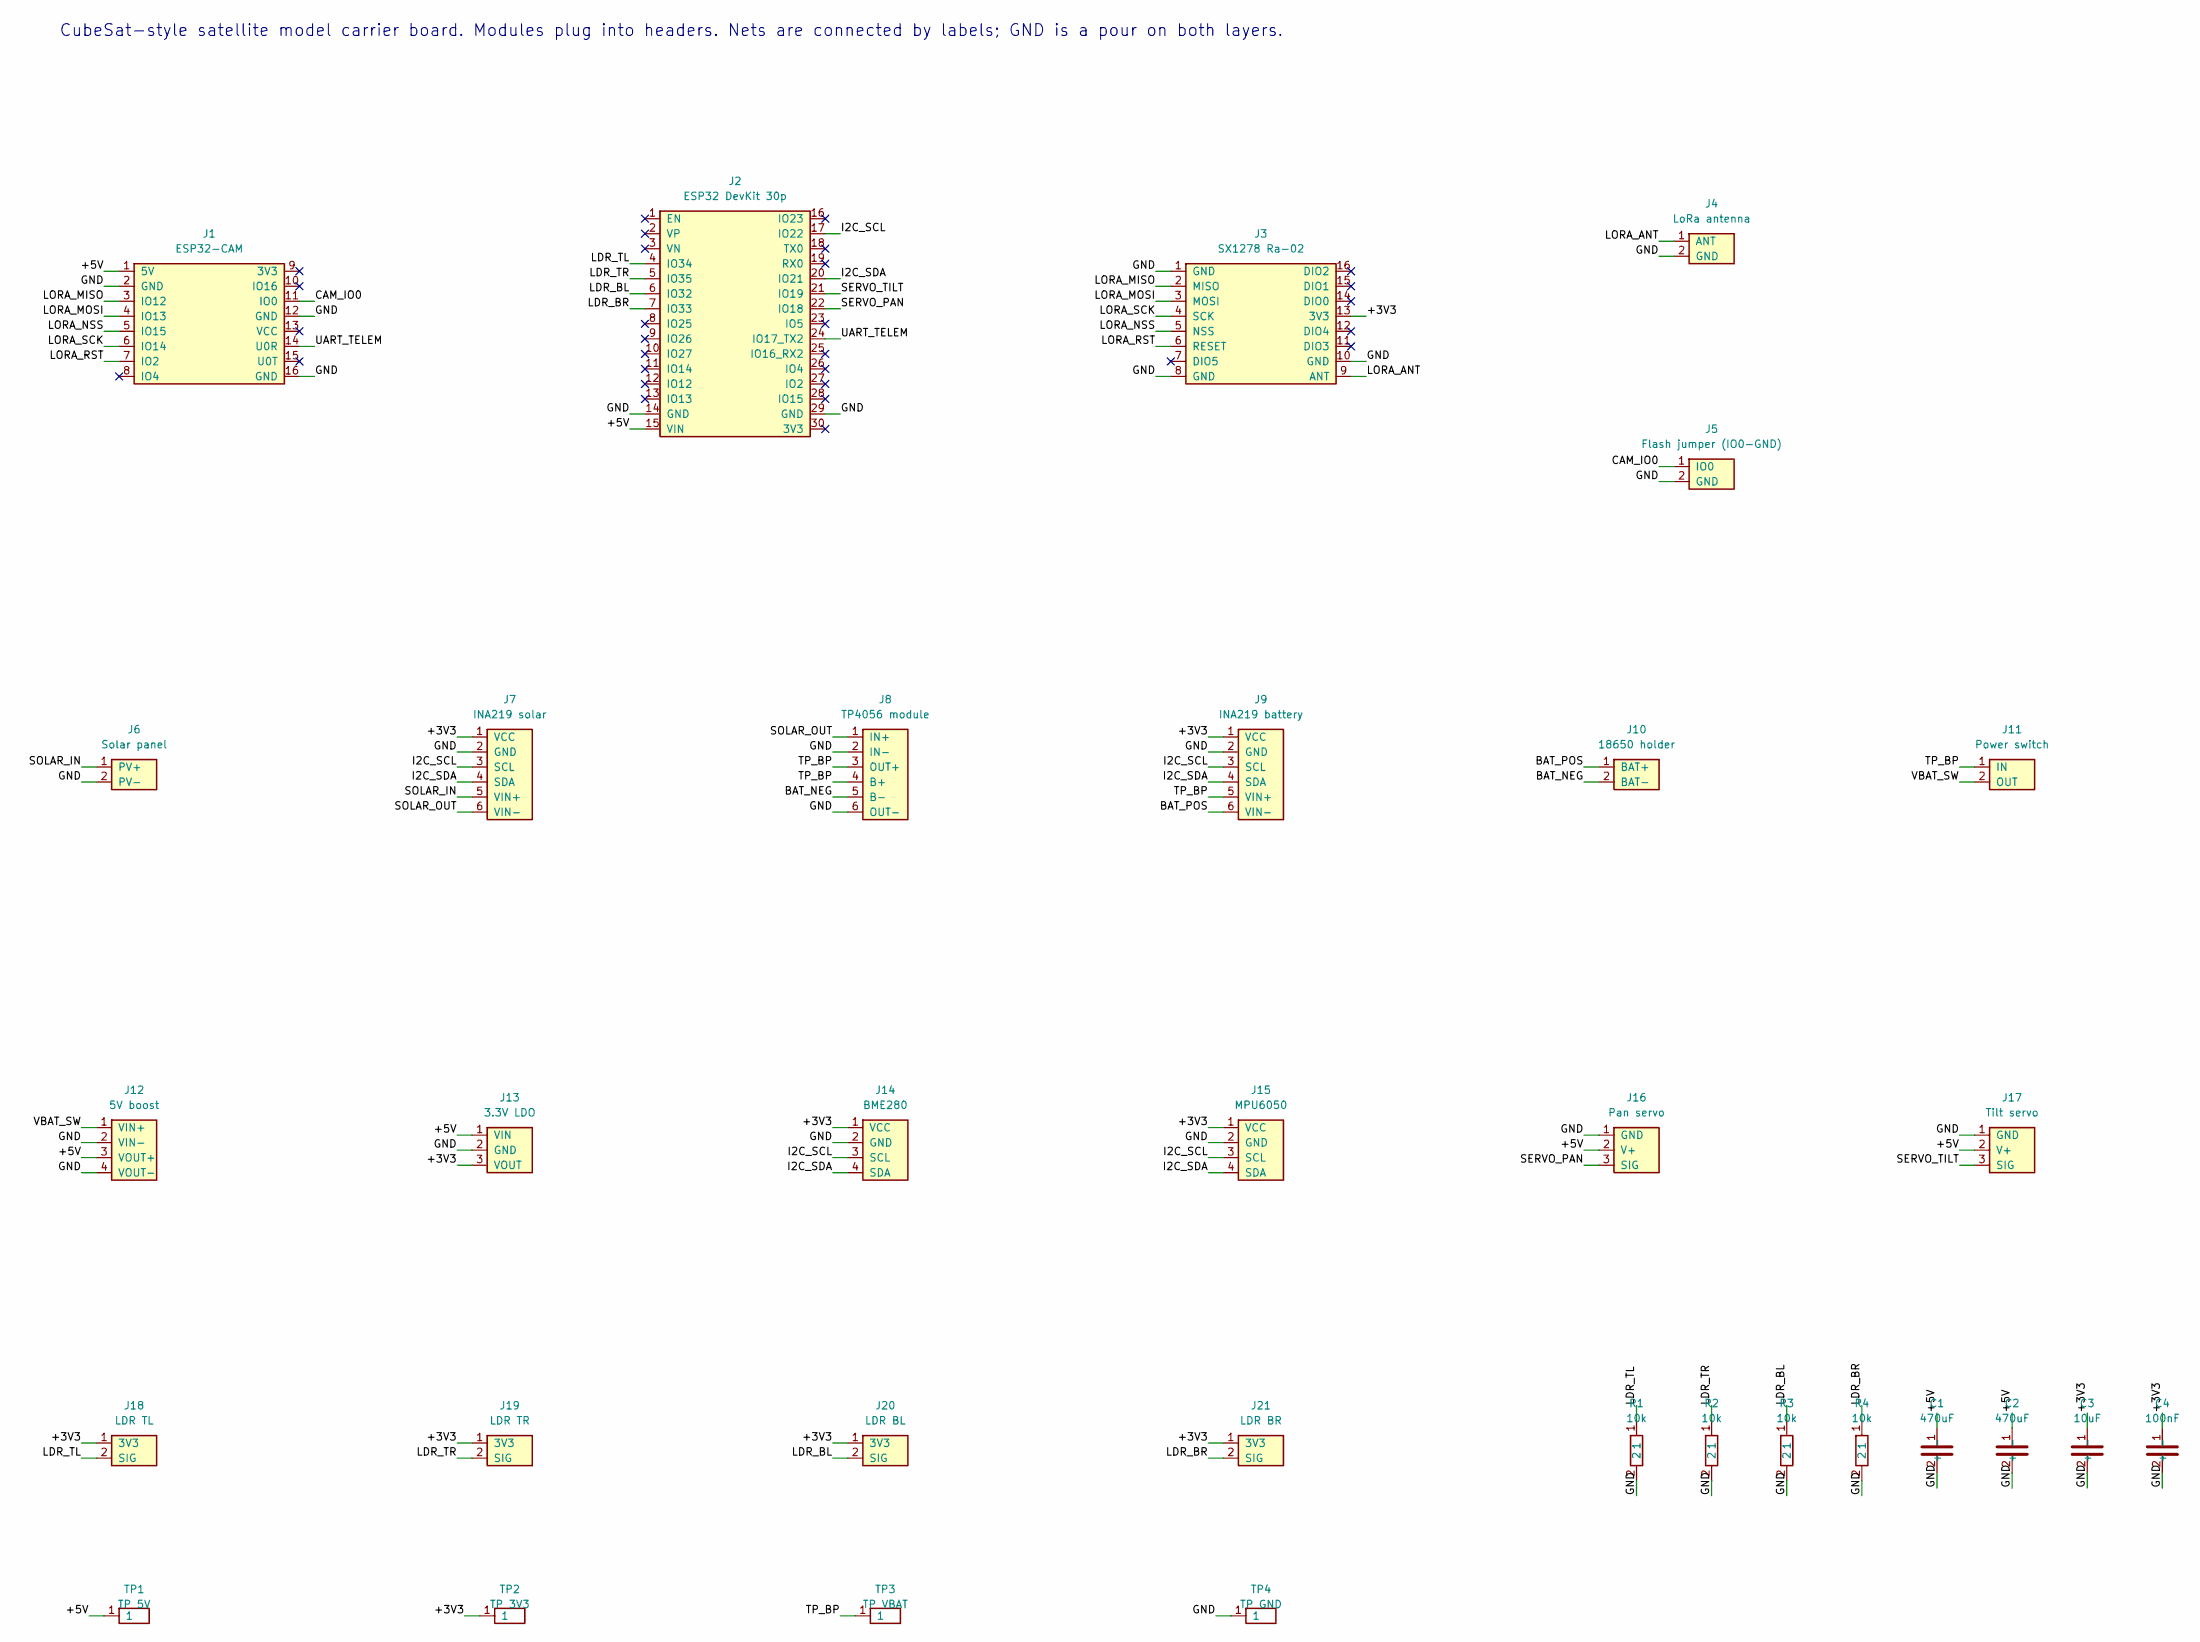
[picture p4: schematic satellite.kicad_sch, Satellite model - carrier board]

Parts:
C1, C2: 470uF; CP_Radial_D8.0mm_P3.50mm
C3: 10uF; C_0805
C4: 100nF; C_0805
J1: ESP32-CAM; ESP32-CAM_Socket_2x08_Row22.86mm
J2: ESP32 DevKit 30p; ESP32_DevKit_30pin_Socket_Row22.86mm
J3: SX1278 Ra-02; SX1278_RA-02_2x08_P2.00mm_Row16mm
J4: LoRa antenna; Header_1x02_P2.54mm_XAxis
J5: Flash jumper (IO0-GND); Header_1x02_P2.54mm_XAxis
J6: Solar panel; Header_1x02_P2.54mm_XAxis
J7: INA219 solar; Header_1x06_P2.54mm_XAxis
J8: TP4056 module; Header_1x06_P2.54mm_XAxis
J9: INA219 battery; Header_1x06_P2.54mm_XAxis
J10: 18650 holder; Header_1x02_P2.54mm_XAxis
J11: Power switch; Header_1x02_P2.54mm_XAxis
J12: 5V boost; Header_1x04_P2.54mm_XAxis
J13: 3.3V LDO; Header_1x03_P2.54mm_XAxis
J14: BME280; Header_1x04_P2.54mm_XAxis
J15: MPU6050; Header_1x04_P2.54mm_XAxis
J16: Pan servo; Header_1x03_P2.54mm_XAxis
J17: Tilt servo; Header_1x03_P2.54mm_XAxis
J18: LDR TL; Header_1x02_P2.54mm_XAxis
J19: LDR TR; Header_1x02_P2.54mm_XAxis
J20: LDR BL; Header_1x02_P2.54mm_XAxis
J21: LDR BR; Header_1x02_P2.54mm_XAxis
R1, R2, R3, R4: 10k; R_0805
TP1: TP 5V; TestPoint_Pad_D2.0mm
TP2: TP 3V3; TestPoint_Pad_D2.0mm
TP3: TP VBAT; TestPoint_Pad_D2.0mm
TP4: TP GND; TestPoint_Pad_D2.0mm

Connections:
+3V3: C3.1, C4.1, J3.13 (3V3), J7.1 (VCC), J9.1 (VCC), J13.3 (VOUT), J14.1 (VCC), J15.1 (VCC), J18.1 (3V3), J19.1 (3V3), J20.1 (3V3), J21.1 (3V3), TP2.1
+5V: C1.1 (+), C2.1 (+), J1.1 (5V), J2.15 (VIN), J12.3 (VOUT+), J13.1 (VIN), J16.2 (V+), J17.2 (V+), TP1.1
BAT_NEG: J8.5 (B-), J10.2 (BAT-)
BAT_POS: J9.6 (VIN-), J10.1 (BAT+)
CAM_IO0: J1.11 (IO0), J5.1 (IO0)
GND: C1.2 (-), C2.2 (-), C3.2, C4.2, J1.2 (GND), J1.12 (GND), J1.16 (GND), J2.14 (GND), J2.29 (GND), J3.1 (GND), J3.8 (GND), J3.10 (GND), J4.2 (GND), J5.2 (GND), J6.2 (PV-), J7.2 (GND), J8.2 (IN-), J8.6 (OUT-), J9.2 (GND), J12.2 (VIN-), J12.4 (VOUT-), J13.2 (GND), J14.2 (GND), J15.2 (GND), J16.1 (GND), J17.1 (GND), R1.2, R2.2, R3.2, R4.2, TP4.1
I2C_SCL: J2.17 (IO22), J7.3 (SCL), J9.3 (SCL), J14.3 (SCL), J15.3 (SCL)
I2C_SDA: J2.20 (IO21), J7.4 (SDA), J9.4 (SDA), J14.4 (SDA), J15.4 (SDA)
LDR_BL: J2.6 (IO32), J20.2 (SIG), R3.1
LDR_BR: J2.7 (IO33), J21.2 (SIG), R4.1
LDR_TL: J2.4 (IO34), J18.2 (SIG), R1.1
LDR_TR: J2.5 (IO35), J19.2 (SIG), R2.1
LORA_ANT: J3.9 (ANT), J4.1 (ANT)
LORA_MISO: J1.3 (IO12), J3.2 (MISO)
LORA_MOSI: J1.4 (IO13), J3.3 (MOSI)
LORA_NSS: J1.5 (IO15), J3.5 (NSS)
LORA_RST: J1.7 (IO2), J3.6 (RESET)
LORA_SCK: J1.6 (IO14), J3.4 (SCK)
SERVO_PAN: J2.22 (IO18), J16.3 (SIG)
SERVO_TILT: J2.21 (IO19), J17.3 (SIG)
SOLAR_IN: J6.1 (PV+), J7.5 (VIN+)
SOLAR_OUT: J7.6 (VIN-), J8.1 (IN+)
TP_BP: J8.3 (OUT+), J8.4 (B+), J9.5 (VIN+), J11.1 (IN), TP3.1
UART_TELEM: J1.14 (U0R), J2.24 (IO17_TX2)
VBAT_SW: J11.2 (OUT), J12.1 (VIN+)

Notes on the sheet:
CubeSat-style satellite model carrier board. Modules plug into headers. Nets are connected by labels; GND is a pour on both layers.

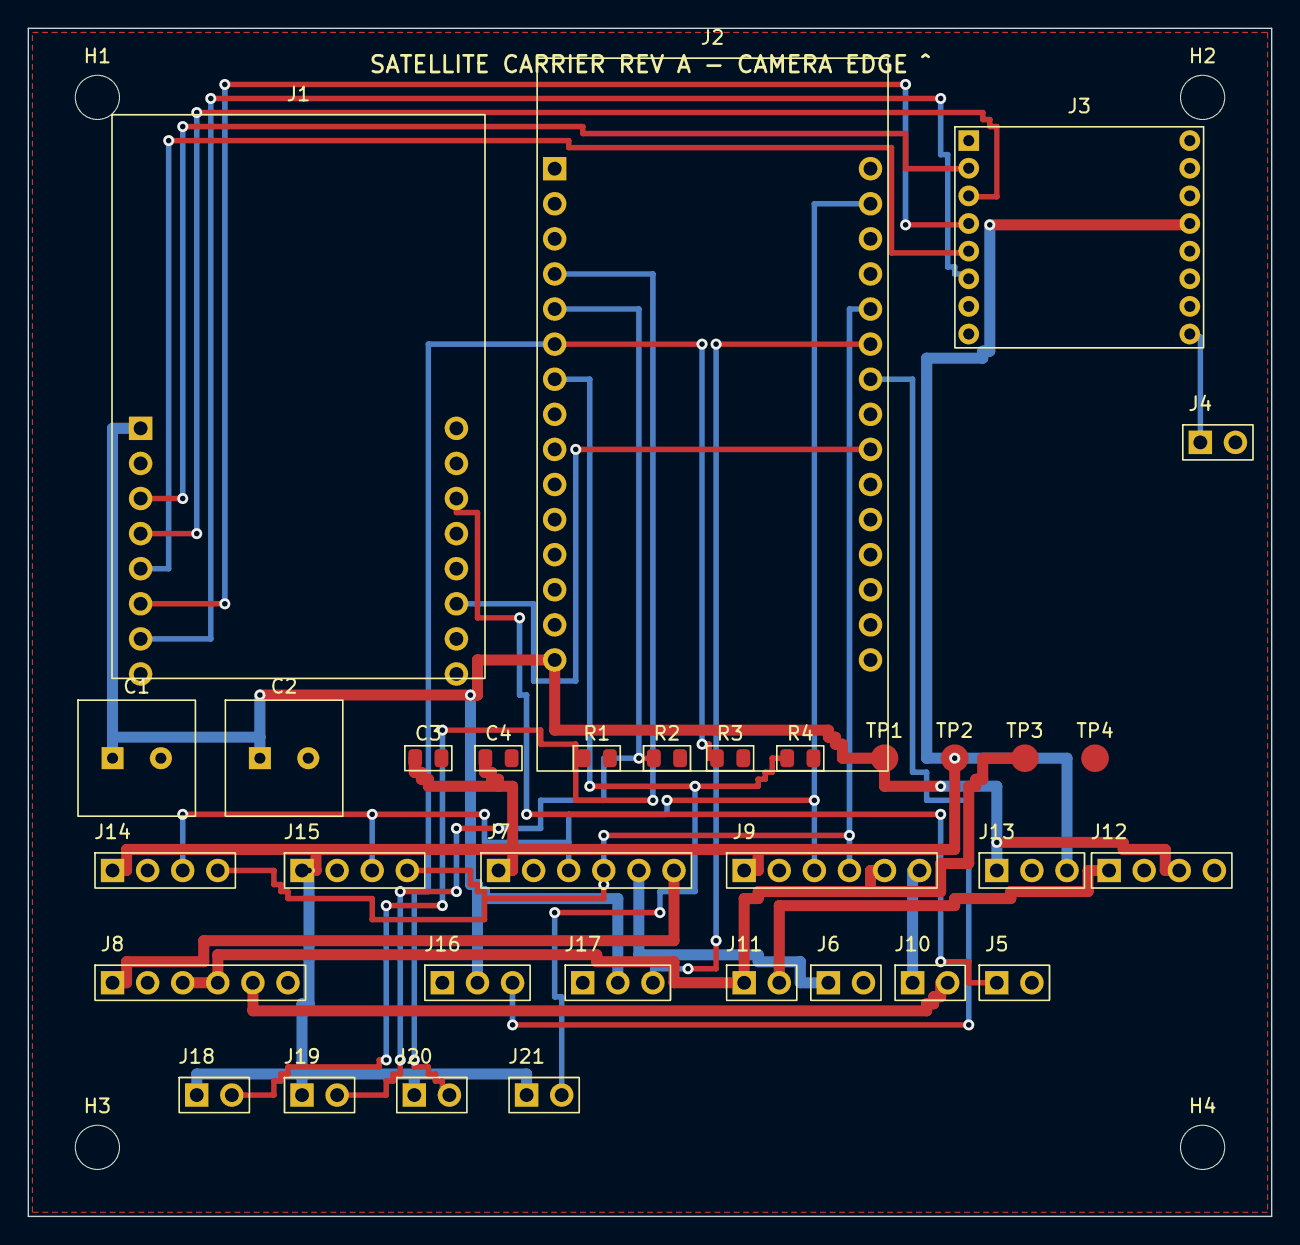
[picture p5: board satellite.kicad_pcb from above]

Board: 2 copper layers, 90.0 x 86.0 mm, 37 parts (0 on the bottom side), 25 nets.

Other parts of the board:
H1, H2, H3, H4: M3; MountingHole_3.2mm_M3

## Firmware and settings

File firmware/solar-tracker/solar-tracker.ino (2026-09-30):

// Solar tracker + telemetry. Board: ESP32 DevKit (30-pin).
// Libraries: ESP32Servo, Adafruit INA219, Adafruit BME280, Adafruit MPU6050, Adafruit Unified Sensor.
#include <Wire.h>
#include <math.h>
#include <ESP32Servo.h>
#include <Adafruit_INA219.h>
#include <Adafruit_BME280.h>
#include <Adafruit_MPU6050.h>

// Pins
#define PIN_PAN   18
#define PIN_TILT  19
#define LDR_TL 34
#define LDR_TR 35
#define LDR_BL 32
#define LDR_BR 33
#define UART_TX2 17   // -> ESP32-CAM RX (GPIO3)
#define UART_RX2 16

// Tracking
#define DEADBAND   150     // ADC counts (0-4095)
#define STEP_DEG   1
#define PAN_MIN 10
#define PAN_MAX 170
#define TILT_MIN 20
#define TILT_MAX 160
#define LOOP_MS 100
#define TELEM_MS 1000

Servo pan, tilt;
int panA = 90, tiltA = 90;
Adafruit_INA219 inaSolar(0x40), inaBatt(0x41);   // solder A0 on the second board for 0x41
Adafruit_BME280 bme;
Adafruit_MPU6050 mpu;
bool okSolar, okBatt, okBme, okMpu;
uint32_t lastTelem = 0;

int readAvg(int pin) {
  long s = 0;
  for (int i = 0; i < 16; i++) s += analogRead(pin);
  return s / 16;
}

void setup() {
  Serial.begin(115200);
  Serial2.begin(115200, SERIAL_8N1, UART_RX2, UART_TX2);
  Wire.begin(21, 22);
  analogReadResolution(12);
  pan.setPeriodHertz(50);  tilt.setPeriodHertz(50);
  pan.attach(PIN_PAN, 500, 2400);
  tilt.attach(PIN_TILT, 500, 2400);
  pan.write(panA); tilt.write(tiltA);
  okSolar = inaSolar.begin();
  okBatt  = inaBatt.begin();
  okBme   = bme.begin(0x76);
  okMpu   = mpu.begin();
  Serial.println("INFO,Solar tracker booting...");
  Serial.printf("INFO,INA_Solar:%d INA_Batt:%d BME280:%d MPU6050:%d\n", okSolar, okBatt, okBme, okMpu);
}

void track() {
  int tl = readAvg(LDR_TL), tr = readAvg(LDR_TR), bl = readAvg(LDR_BL), br = readAvg(LDR_BR);
  int top = (tl + tr) / 2, bot = (bl + br) / 2;
  int left = (tl + bl) / 2, right = (tr + br) / 2;
  // Flip signs if your mechanics move the wrong way
  if (abs(top - bot) > DEADBAND)   tiltA += (top > bot) ? STEP_DEG : -STEP_DEG;
  if (abs(left - right) > DEADBAND) panA += (left > right) ? -STEP_DEG : STEP_DEG;
  panA = constrain(panA, PAN_MIN, PAN_MAX);
  tiltA = constrain(tiltA, TILT_MIN, TILT_MAX);
  pan.write(panA); tilt.write(tiltA);
}

void telemetry() {
  float sv = okSolar ? inaSolar.getBusVoltage_V() : 0, sm = okSolar ? inaSolar.getCurrent_mA() : 0;
  float bv = okBatt ? inaBatt.getBusVoltage_V() : 0,  bm = okBatt ? inaBatt.getCurrent_mA() : 0;
  float t = okBme ? bme.readTemperature() : 0, p = okBme ? bme.readPressure() / 100.0 : 0, h = okBme ? bme.readHumidity() : 0;
  float pitch = 0, roll = 0;
  if (okMpu) {
    sensors_event_t a, g, tmp;
    mpu.getEvent(&a, &g, &tmp);
    pitch = atan2(a.acceleration.x, sqrt(a.acceleration.y * a.acceleration.y + a.acceleration.z * a.acceleration.z)) * 57.2958;
    roll  = atan2(a.acceleration.y, a.acceleration.z) * 57.2958;
  }
  char line[160];
  snprintf(line, sizeof(line), "T,%.2f,%.0f,%.2f,%.0f,%.1f,%.1f,%.0f,%.0f,%.0f,%d,%d",
           sv, sm, bv, bm, t, p, h, pitch, roll, panA, tiltA);
  Serial2.println(line);
  Serial.println(line);
}

void loop() {
  track();
  if (millis() - lastTelem >= TELEM_MS) { lastTelem = millis(); telemetry(); }
  delay(LOOP_MS);
}

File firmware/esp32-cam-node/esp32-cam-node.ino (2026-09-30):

// ESP32-CAM node: capture JPEG, send over LoRa in CRC-protected chunks, deep sleep.
// Board: AI Thinker ESP32-CAM. Library: LoRa (Sandeep Mistry).
// Telemetry arrives as a text line on UART0 RX (GPIO3) from the tracker MCU.
// Disconnect that wire while flashing.
#include "esp_camera.h"
#include <SPI.h>
#include <LoRa.h>
#include "driver/gpio.h"

// ---- Config ----
#define SLEEP_SECONDS   60
#define LORA_FREQ       433E6   // use your region's legal band
#define LORA_SF         7
#define LORA_BW         125E3
#define CHUNK           200
#define TYPE_IMG        0x10
#define TYPE_TELEM      0x20

// LoRa SX1278 pins (TX only, DIO0 not used)
#define LORA_SCK  14
#define LORA_MISO 12
#define LORA_MOSI 13
#define LORA_SS   15
#define LORA_RST  2

// AI Thinker camera pins
#define PWDN_GPIO_NUM 32
#define RESET_GPIO_NUM -1
#define XCLK_GPIO_NUM 0
#define SIOD_GPIO_NUM 26
#define SIOC_GPIO_NUM 27
#define Y9_GPIO_NUM 35
#define Y8_GPIO_NUM 34
#define Y7_GPIO_NUM 39
#define Y6_GPIO_NUM 36
#define Y5_GPIO_NUM 21
#define Y4_GPIO_NUM 19
#define Y3_GPIO_NUM 18
#define Y2_GPIO_NUM 5
#define VSYNC_GPIO_NUM 25
#define HREF_GPIO_NUM 23
#define PCLK_GPIO_NUM 22

RTC_DATA_ATTR uint8_t imgId = 0;

uint16_t crc16(const uint8_t *d, size_t n) {
  uint16_t c = 0xFFFF;
  while (n--) {
    c ^= (uint16_t)(*d++) << 8;
    for (int i = 0; i < 8; i++) c = (c & 0x8000) ? (c << 1) ^ 0x1021 : (c << 1);
  }
  return c;
}

void sendPacket(uint8_t type, uint8_t id, uint16_t seq, uint16_t total, const uint8_t *p, uint8_t len) {
  uint8_t buf[7 + CHUNK + 2];
  buf[0] = type; buf[1] = id;
  buf[2] = seq >> 8;   buf[3] = seq & 0xFF;
  buf[4] = total >> 8; buf[5] = total & 0xFF;
  buf[6] = len;
  memcpy(buf + 7, p, len);
  uint16_t c = crc16(buf, 7 + len);
  buf[7 + len] = c >> 8;
  buf[8 + len] = c & 0xFF;
  LoRa.beginPacket();
  LoRa.write(buf, 9 + len);
  LoRa.endPacket();      // blocking until TX done
  delay(20);
}

bool camReady = false;

String readTelemetry(uint32_t timeoutMs) {
  String last = "";
  String line = "";
  uint32_t t0 = millis();
  while (millis() - t0 < timeoutMs) {
    while (Serial.available()) {
      char ch = Serial.read();
      if (ch == '\n') { if (line.startsWith("T,")) last = line; line = ""; }
      else if (ch != '\r' && line.length() < 180) line += ch;
    }
    if (last.length()) break;
  }
  return last;
}

bool initCamera() {
  camera_config_t c = {};
  c.ledc_channel = LEDC_CHANNEL_0; c.ledc_timer = LEDC_TIMER_0;
  c.pin_d0 = Y2_GPIO_NUM; c.pin_d1 = Y3_GPIO_NUM; c.pin_d2 = Y4_GPIO_NUM; c.pin_d3 = Y5_GPIO_NUM;
  c.pin_d4 = Y6_GPIO_NUM; c.pin_d5 = Y7_GPIO_NUM; c.pin_d6 = Y8_GPIO_NUM; c.pin_d7 = Y9_GPIO_NUM;
  c.pin_xclk = XCLK_GPIO_NUM; c.pin_pclk = PCLK_GPIO_NUM;
  c.pin_vsync = VSYNC_GPIO_NUM; c.pin_href = HREF_GPIO_NUM;
  c.pin_sccb_sda = SIOD_GPIO_NUM; c.pin_sccb_scl = SIOC_GPIO_NUM;
  c.pin_pwdn = PWDN_GPIO_NUM; c.pin_reset = RESET_GPIO_NUM;
  c.xclk_freq_hz = 20000000;
  c.pixel_format = PIXFORMAT_JPEG;
  c.frame_size = FRAMESIZE_QQVGA;   // 160x120
  c.jpeg_quality = 15;              // higher number = smaller file
  c.fb_count = 1;
  camReady = (esp_camera_init(&c) == ESP_OK);
  return camReady;
}

void goToSleep() {
  LoRa.sleep();
  if (camReady) esp_camera_deinit();
  pinMode(PWDN_GPIO_NUM, OUTPUT);
  digitalWrite(PWDN_GPIO_NUM, HIGH);          // camera power-down
  gpio_hold_en((gpio_num_t)PWDN_GPIO_NUM);
  gpio_deep_sleep_hold_en();
  Serial.flush();
  esp_sleep_enable_timer_wakeup((uint64_t)SLEEP_SECONDS * 1000000ULL);
  esp_deep_sleep_start();
}

void setup() {
  gpio_hold_dis((gpio_num_t)PWDN_GPIO_NUM);
  Serial.begin(115200);
  String telem = readTelemetry(3000);

  SPI.begin(LORA_SCK, LORA_MISO, LORA_MOSI, LORA_SS);
  LoRa.setPins(LORA_SS, LORA_RST, -1);
  if (!LoRa.begin(LORA_FREQ)) {
    Serial.println("ERR,LoRa init failed");
    goToSleep();
  }
  LoRa.setSpreadingFactor(LORA_SF);
  LoRa.setSignalBandwidth(LORA_BW);
  LoRa.setCodingRate4(5);
  LoRa.setTxPower(17);
  LoRa.enableCrc();

  if (telem.length()) sendPacket(TYPE_TELEM, imgId, 0, 1, (const uint8_t *)telem.c_str(), telem.length());

  if (initCamera()) {
    for (int i = 0; i < 3; i++) { camera_fb_t *f = esp_camera_fb_get(); if (f) esp_camera_fb_return(f); }
    camera_fb_t *fb = esp_camera_fb_get();
    if (fb) {
      uint16_t total = (fb->len + CHUNK - 1) / CHUNK;
      for (uint16_t s = 0; s < total; s++) {
        size_t off = (size_t)s * CHUNK;
        uint8_t n = min((size_t)CHUNK, fb->len - off);
        sendPacket(TYPE_IMG, imgId, s, total, fb->buf + off, n);
      }
      esp_camera_fb_return(fb);
      imgId++;
    }
  } else {
    Serial.println("ERR,camera init failed");
  }
  goToSleep();
}

void loop() {}

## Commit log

2026-09-30 Initial commit: CubeSat-style satellite model with solar tracker, payload, LoRa telemetry, KiCad PCB and OpenSCAD CAD
    [bom.csv, netlist.csv, satellite.kicad_pcb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]
2026-09-30 Add production-ready RS-274X Gerber and Excellon drill files (hardware/gerbers.zip)
    [satellite-B_Cu.gbr, satellite-B_Mask.gbr, satellite-Edge_Cuts.gbr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]
2026-09-30 Add 3D model render and Gerber fabrication previews to README

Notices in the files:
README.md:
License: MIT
